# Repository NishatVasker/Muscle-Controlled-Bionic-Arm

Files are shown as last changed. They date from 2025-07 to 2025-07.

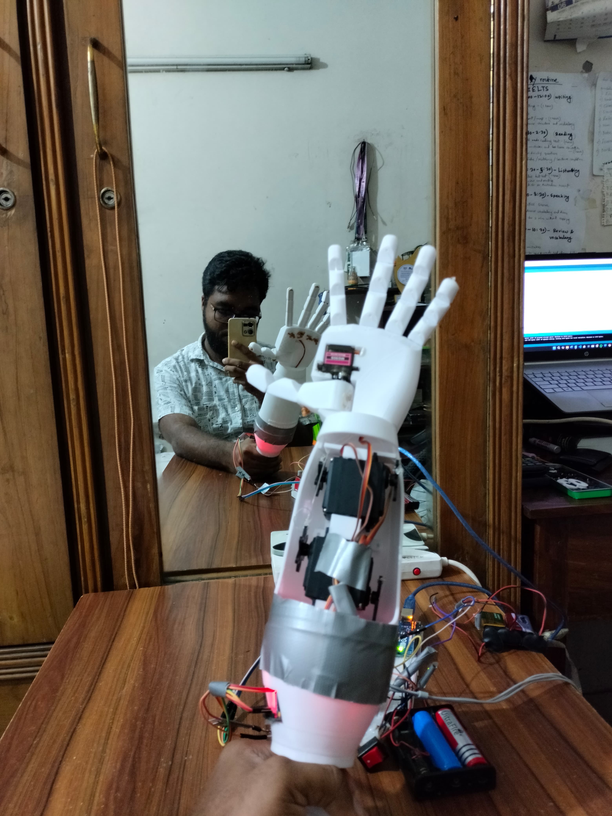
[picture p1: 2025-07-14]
Image and Video/Bionic_arm_media (1).jpg

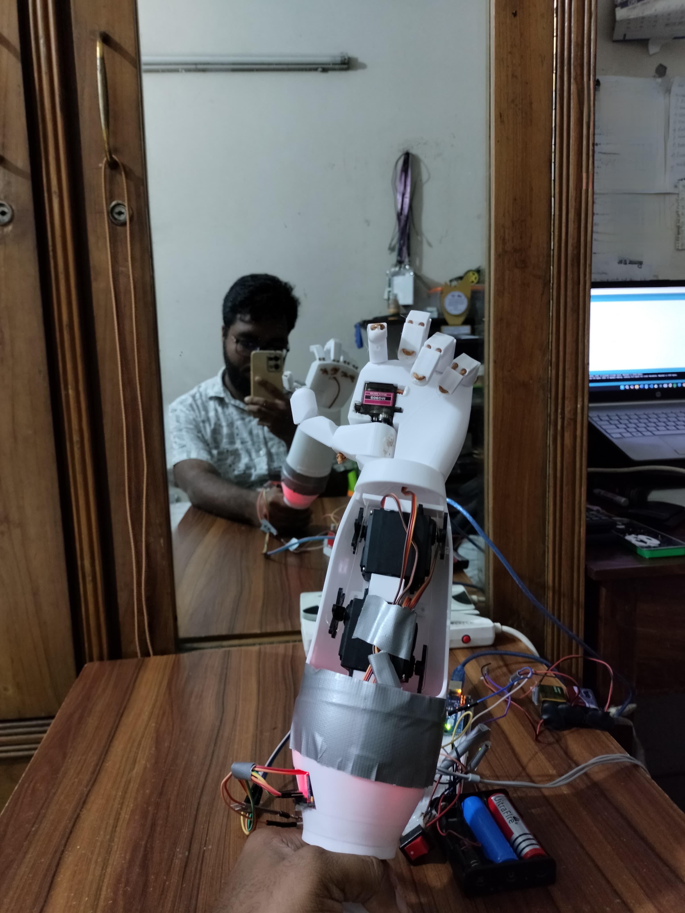
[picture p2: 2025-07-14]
Image and Video/Bionic_arm_media (14).jpg

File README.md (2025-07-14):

# Muscle-Controlled-Bionic-Arm
# 💪 EMG-Controlled Bionic Arm | Arduino + Muscle Sensor + 3D Printed

This open-source project demonstrates a **bionic arm controlled via EMG (Electromyographic) muscle signals**, designed for two core applications:

1. Assisting **people without a left arm** as a low-cost prosthetic solution.  
2. Serving as a functional **robotic limb for humanoid robots**.

The system uses **muscle signals** from a forearm to control **five servo motors** that replicate human hand motions in real-time.

Bionic_arm_media (11)

---

## 🎯 Features

- EMG-based real-time motor control using Arduino  
- Five degrees of motion via MG996R servos  
- PCA9685 for efficient servo signal handling  
- Fully 3D printed modular arm (lightweight, 400g)  
- Cost-effective and prosthetic-friendly design  
- Can be extended for humanoid robotics

---

## 🧰 Components Used

| Component | Description / Quantity |
|---|---|
| Arduino Uno | Microcontroller (1x) |
| MG996R Servo Motors  | High-torque motors (5x) |
| PCA9685 Servo Driver | 16-channel PWM driver (1x) |
| EMG Muscle Sensor | Generic sensor (1x) |
| 9V Batteries | For EMG sensor power (2x) |
| 3D Printed Arm | PLA, 30% infill, total ~400g |
| Jumper Wires | For connections |

---

## 🧠 How It Works

- EMG sensor detects electrical activity from your forearm muscles.  
- Arduino reads the EMG signal as analog input.  
- Signal is mapped to servo angles using threshold-based control.  
- PCA9685 generates PWM signals for servo motors.  
- Servo motors rotate fingers/wrist to mimic hand movement.

---

## 🔌 Full Wiring Connections

This section details all the electrical connections between the microcontroller, sensor, servo motors, servo driver, and batteries. It assumes you're using an **Arduino Uno**, **5 MG996R servos**, **a PCA9685 servo driver**, and a **generic EMG muscle sensor** powered by two 9V batteries.

---

### 🧠 EMG Sensor → Arduino Uno

| EMG Sensor Pin | Connects To |
|---|---|
| VCC | +9V Battery 1 |
| GND | GND of Battery 1 and Arduino GND |
| SIG (OUT) | Arduino A0 (Analog Input)  |

> 🔋 Power the EMG sensor using **two 9V batteries in series** for ±9V operation (as many analog EMG modules require). Ensure the Arduino shares a **common ground** with the battery.

---

### 🔧 PCA9685 Servo Driver → Arduino Uno (I2C)

| PCA9685 Pin | Arduino Uno Pin |
|---|---|
| VCC | 5V |
| GND | GND |
| SDA | A4 |
| SCL | A5 |

> 🧠 This sets up I2C communication for servo control.

---

### ⚙️ Servo Motors (MG996R) → PCA9685 Channels 0–4

| Servo | PCA9685 Channel | Signal Pin | VCC (Red) | GND (Brown) |
|---|---|---|---|---|
| Thumb Servo | 0 | CH0 | 5V Power  | Common GND  |
| Index Servo | 1 | CH1 | 5V Power  | Common GND  |
| Middle Servo  | 2 | CH2 | 5V Power  | Common GND  |
| Ring Servo | 3 | CH3 | 5V Power  | Common GND  |
| Wrist Servo | 4 | CH4 | 5V Power  | Common GND  |

> ⚠️ Do **not power servos from Arduino 5V pin**. Use a **separate 5V–6V external power source** (e.g., 2-cell Li-ion battery or 5V/3A adapter) to VCC of PCA9685 servo rail.

---

### 🔋 Power Supply Summary

| Device | Power Source | Notes |
|---|---|---|
| Arduino Uno | USB or 9V adapter | Can be USB-powered during testing |
| PCA9685 (logic)  | Arduino 5V | Connected via VCC pin |
| Servo Motors | External 5–6V (2–5A) | Do not use Arduino 5V for servos |
| EMG Sensor | Two 9V batteries (±9V) | Sensor output to Arduino A0 |

---

### 🧷 Common Ground Wiring (Very Important!)

You **must connect all GNDs together**:
- Arduino GND
- PCA9685 GND
- EMG sensor GND
- Servo motor power GND
- 9V battery GND (used in EMG)

This ensures a stable reference voltage for analog signal reading and PWM control.

---

### 🖼️ Suggested Diagram (Optional, generated with GPT from microcontroller code)

 

---

## 📐 Mathematical Mapping

Let `V_emg` be the EMG analog signal. The angle θ for servo is calculated as:

- If `V_emg < 250`, then `θ = 0°`  
- Else, map `V_emg` from 250–600 to 0–180°

```cpp
if (V_emg > threshold) {
  angle = map(V_emg, 250, 600, 0, 180);
} else {
  angle = 0;
}
```  

## 🧾 Pseudocode
Start
Initialize I2C and PCA9685
Loop:
    Read EMG signal from A0
    If signal > threshold:
        Map signal to angle
        Move all 5 servos to that angle
    Else:
        Set servos to 0°
Repeat

## 📹 Video

🎥 Watch the Bionic Arm in Action:  
➡️ [https://www.youtube.com/shorts/qkh9qTzFNlg](https://www.youtube.com/shorts/qkh9qTzFNlg)

https://github.com/user-attachments/assets/264a68eb-bbef-4f23-b577-94a843c432ea

Bionic_arm_media (11)
Bionic_arm_media (6)
Bionic_arm_media (5)

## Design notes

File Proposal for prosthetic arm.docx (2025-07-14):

## Prosthetic Arm Controlling with EMG Muscle Sensor

### 1. Title

Smart, Affordable Prosthetic Arm: A 3D-Printed Muscle-Controlled Assistive System for Human and Robotic Use

### 2. Introduction

Prosthetic limbs are critical tools for individuals who have suffered limb loss, enabling them to regain essential functionality and independence. However, advanced prosthetic technologies often remain inaccessible due to high costs and limited availability in developing regions. This project proposes a cost-effective, 3D-printed prosthetic arm controlled via electromyography (EMG) muscle sensors. It is designed to be functional, affordable, and accessible for both human and robotic applications.

### 3. Uniqueness of the Project

- Fully 3D-printed design with a weight of 400g and modular assembly.
- Integrated with a high-quality EMG sensor that interprets muscle movement into real-time servo control.
- Uses open-source components and code, promoting educational and research use.
- Designed to serve both amputees and robotic platforms, which is rare in low-cost prosthetics.
- Utilises standard MG996R and MG90S servo motors for mechanical actuation, with tendons formed from fishing line and paracord.

### 4. Research Gap

- Most low-cost prosthetic solutions lack intuitive EMG control.
- Current open-source robotic hand models are not typically adapted for real-world prosthetics.
- Limited research on EMG-controlled arms that are 3D-printed, modular, and open-source, particularly with affordable hardware suited for developing countries.

### 5. Market Value and Usefulness

- For amputees: Provides basic hand functionality such as grasping, pinching, and releasing.
- In robotics: Serves as a human-like actuator controlled via EMG or other signals for gesture replication.
- In education: Enables students to explore concepts in biomedical engineering, mechatronics, and robotics.
- Market potential: High in countries with limited access to advanced prosthetics. Potential for NGOs, assistive tech startups, and robotics labs.

### 6. Integration for Humans and Robots

- Human use: Surface EMG electrodes are placed on the forearm muscles. Signals are read and translated into joint movement using an Arduino.
- Robotic use: The EMG input can be replaced with digital or AI-based signals, allowing it to act as a programmable robotic manipulator.

### 7. Manufacturing Process

Step | Description
3D Design | Used open-source design from grossrc
3D Printing | PLA filament, 10–30% infill, ~400g
Mechanical Assembly | 5 servo motors, tendon routing, glue
Electrical Setup | Arduino Uno, PCA9685 driver, EMG sensor
Coding and Signal Processing | Arduino IDE, EMG input filtering
Testing | Manual and EMG signal test via servo tester

### 8. Components and Specifications

Component | Specification | Quantity | Source
MG996R Servo Motor | Torque ~1.2–1.5 Nm, 180° rotation | 4 | RoboticsBD
MG90S Micro Servo | 180° rotation, lightweight finger control | 1 | RoboticsBD
Arduino Uno R3 | ATmega328P Microcontroller | 1 | RoboticsBD
PCA9685 16-Channel Servo Driver | 12-bit PWM resolution | 1 | RoboticsBD
EMG Muscle Sensor Kit | Surface electrodes, signal conditioner | 1 | RoboticsBD
Breadboard, Wires, USB Cable, Glue Stick,etc | Standard electronics | Various | RoboticsBD
3D Printed Hand | Humanoid design from grossrc (Thingiverse) | 1 | Local print

### 9. Pseudocode for Control Logic

Start System

Initialize Arduino, EMG Sensor, PCA9685, Servo Pins

LOOP:

Read analog EMG signal from muscle sensor

IF signal > threshold:

Normalize signal to angle range (0–180)

Map angle to corresponding servo for finger movement

Send angle as PWM output to each servo via PCA9685

ELSE:

Set all servos to rest position

End Loop

## 9. Analytical and Logical Control Design for EMG-Controlled Prosthetic Arm

### 9.1 System Logic Overview

The control loop transforms human muscle signals into finger movement using signal processing, linear mapping, and servo actuation.

#### Signal Flow Architecture:

1. EMG Sensor (Analogue Signal)

↓

2. ADC Conversion (10-bit: 0–1023)

↓

3. Noise Filtering (EMA Filter)

↓

4. Signal Thresholding (rest vs active)

↓

5. Normalisation to intensity (0–1)

↓

6. Mapping intensity to servo angle (0°–180°)

↓

7. Convert angle to PWM (pulse width)

↓

8. Servo actuation via PCA9685

### 9.2 Mathematical Breakdown

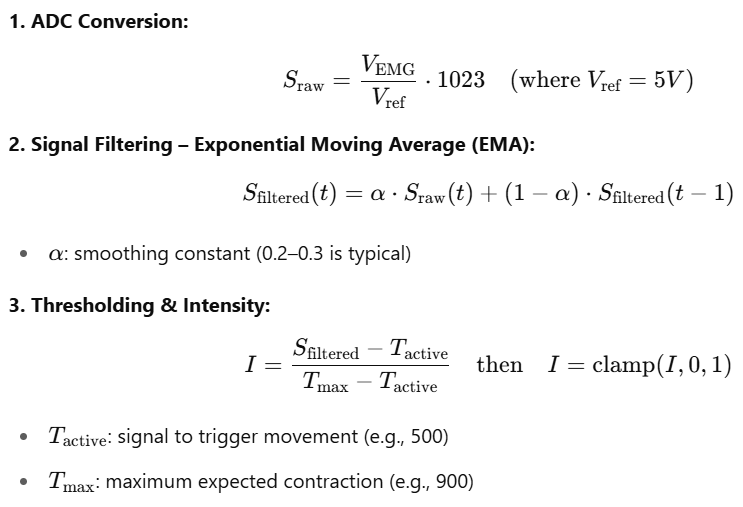
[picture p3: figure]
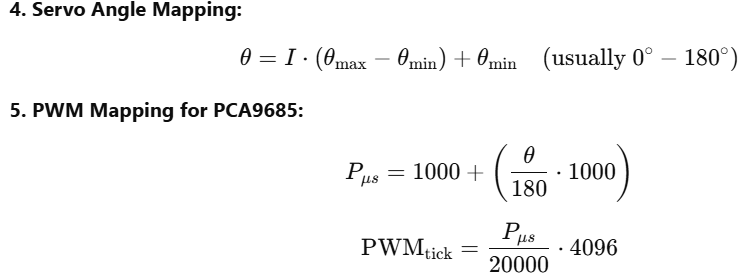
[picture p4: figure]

### 9.3 Final Control Logic – Pseudocode

START

// --- INITIALISATION ---

Set EMG_input_pin = A0

Set smoothing_alpha = 0.2

Set θ_min = 0°, θ_max = 180°

Set PWM_min = 1000 μs, PWM_max = 2000 μs

Set threshold_rest = 400

Set threshold_active = 500

Set signal_max = 900

Initialize PCA9685 (I2C)

Attach servos to channels: [thumb, index, middle, ring, pinky]

Set all servos to neutral (90°)

// --- MAIN LOOP ---

Loop Forever:

// Step 1: Read EMG analog value

raw_signal = analogRead(EMG_input_pin)

// Step 2: Apply Exponential Moving Average Filter

filtered_signal = (smoothing_alpha × raw_signal) + ((1 - smoothing_alpha) × filtered_signal_previous)

filtered_signal_previous = filtered_signal

// Step 3: Check if signal is above rest threshold

If filtered_signal < threshold_rest:

Set all servos to rest (θ = 90°)

continue

// Step 4: Calculate contraction intensity

intensity = (filtered_signal - threshold_active) / (signal_max - threshold_active)

intensity = Clamp between [0, 1]

// Step 5: Convert intensity to angle

θ = θ_min + intensity × (θ_max - θ_min)

// Step 6: Convert angle to pulse width

P = PWM_min + (θ / 180) × (PWM_max - PWM_min)

PWM_tick = (P / 20000) × 4096

// Step 7: Send PWM tick to all servos

For each servo in [thumb, index, middle, ring, pinky]:

Set PWM_tick on corresponding PCA9685 channel

// Step 8: Small delay to avoid jitter

delay(10 ms)

END LOOP

END

### 9.4 Engineering Notes and Optimisations

#### Dynamic Signal Ranges:

- Muscle strength varies per user. Calibration can be performed by taking average resting EMG for 5 seconds and setting that as threshold_rest.

#### Safety Enhancements:

- Implement watchdog timers: If signal drops or noise spikes > 1 sec, reset system.
- Limit servos between 10° and 170° to avoid binding.

#### Multichannel EMG (Advanced Scope):

- For advanced versions, use multiple EMG sensors to differentiate thumb and finger contractions.

### 9.5 Numerical Example

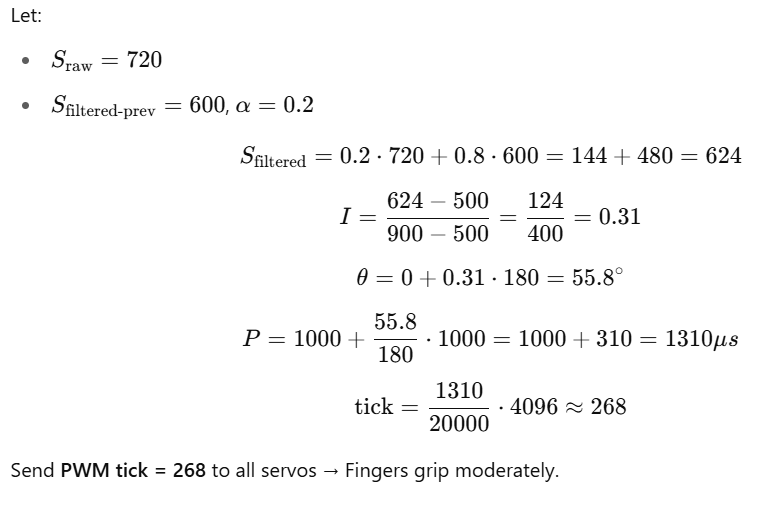
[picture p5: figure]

### 10. Mathematical Analysis

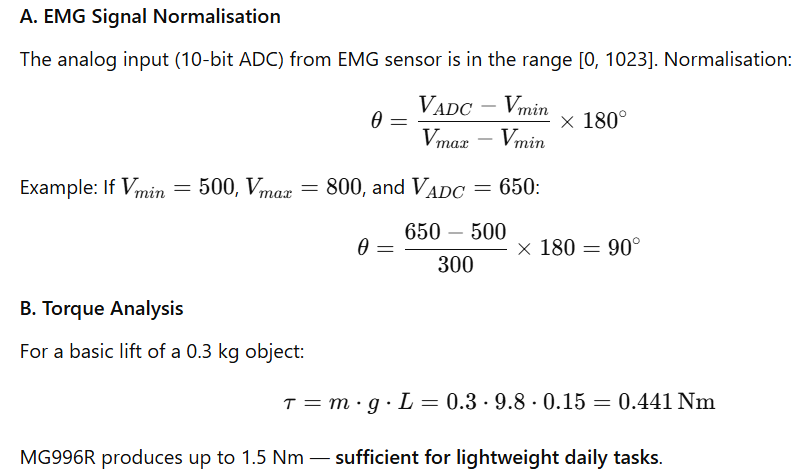
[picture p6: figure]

### 11. Budget Summary

Item Category | Cost (BDT)
Electronics (purchased) | 6,862
3D Printing (400g arm) | 4,000
Miscellaneous (tools, glue) | 2000
Total Cost | 12,862

( This price can be changed anytime due to high pricing of shipment from CHINA)

### 12. Conclusion

This project demonstrates a cost-effective, functional prosthetic arm that uses EMG muscle signals for natural control. Its affordability, modularity, and open-source nature position it as a valuable innovation in both healthcare and robotics. The system can be enhanced with gesture recognition, AI algorithms, or remote robotic integration, offering future development opportunities.

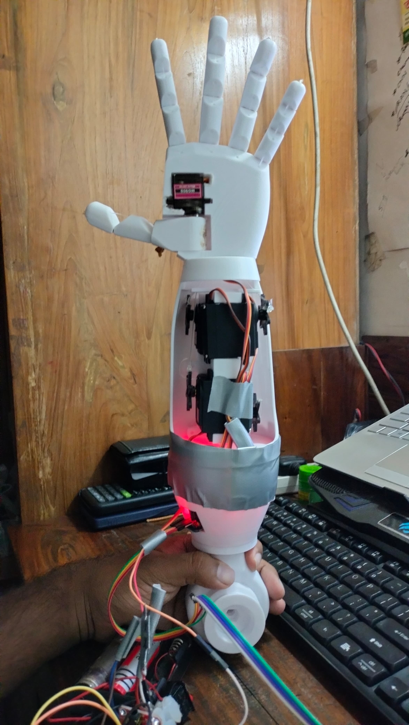
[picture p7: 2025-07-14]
Image and Video/Bionic_arm_media (9).jpg

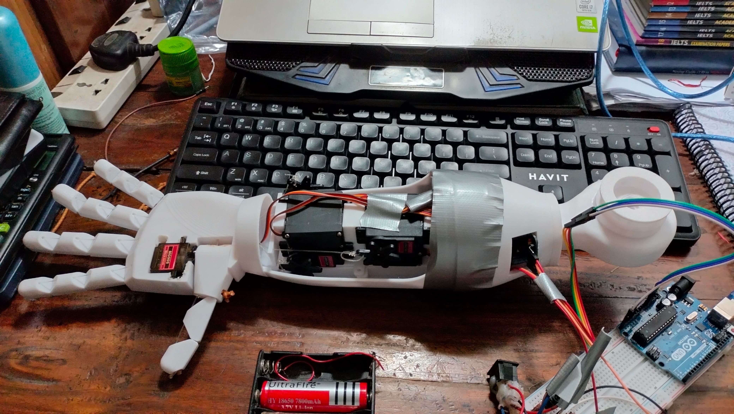
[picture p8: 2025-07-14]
Image and Video/Bionic_arm_media (11).jpg

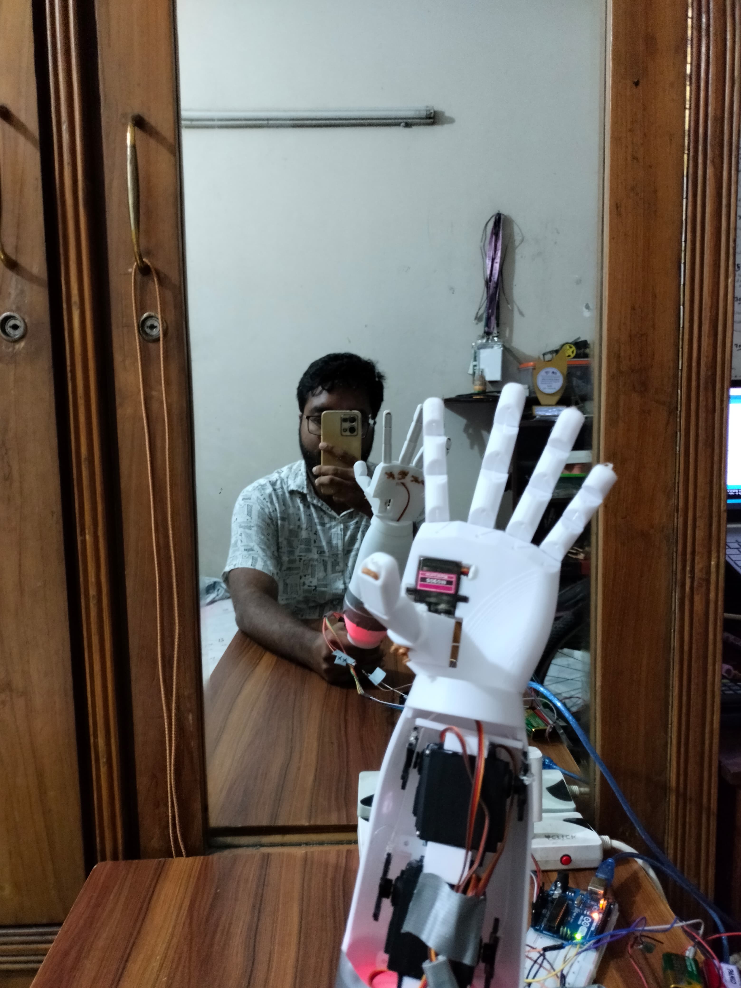
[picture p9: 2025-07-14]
Image and Video/Bionic_arm_media (4).jpg

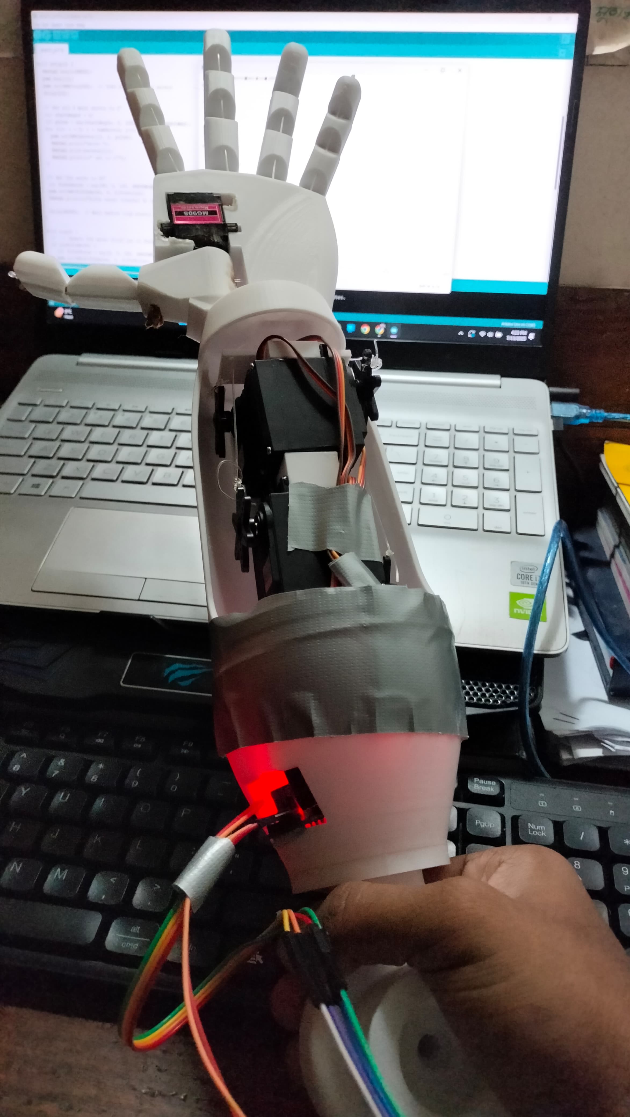
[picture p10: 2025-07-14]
Image and Video/Bionic_arm_media (10).jpg

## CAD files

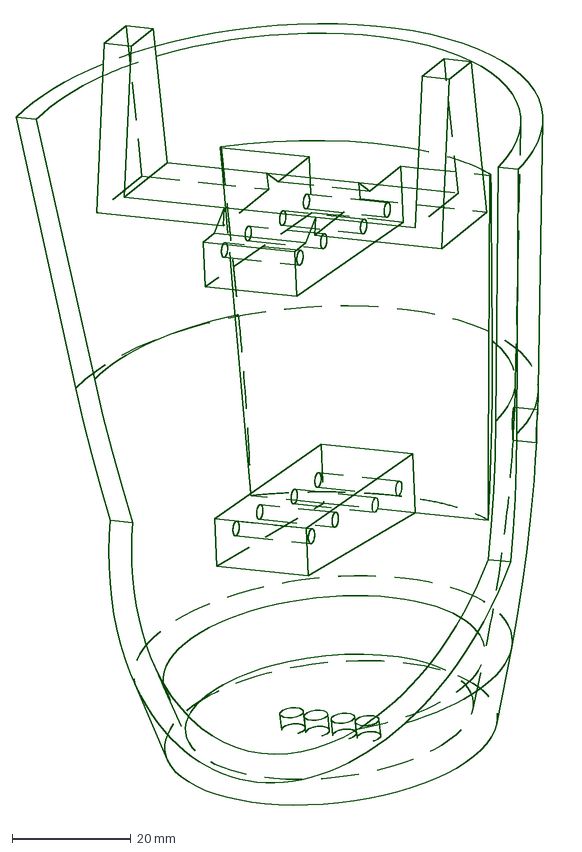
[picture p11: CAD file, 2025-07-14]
files/Piece_1.dxf
92.4 x 133.9 mm

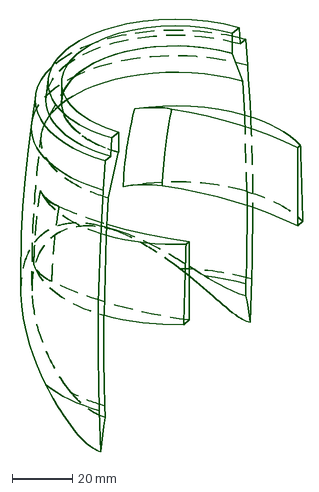
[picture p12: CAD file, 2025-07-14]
files/PC2-2_Cover.dxf
95.2 x 144.6 mm

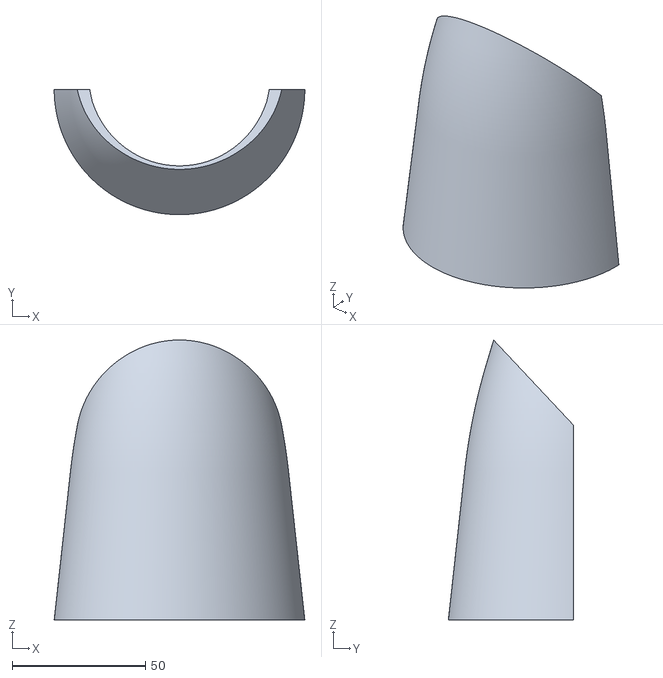
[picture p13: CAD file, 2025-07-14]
files/PC1_Cover.stl
94.0 x 47.0 x 105.0

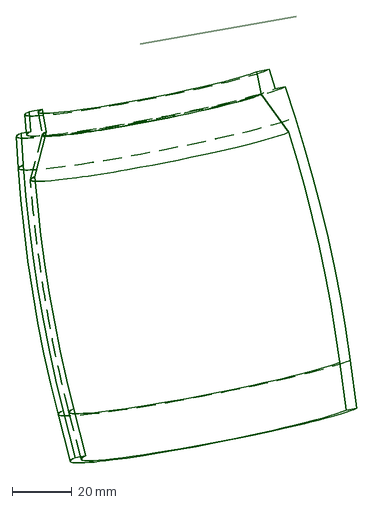
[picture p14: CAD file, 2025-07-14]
files/Piece_2.dxf
113.6 x 149.6 mm

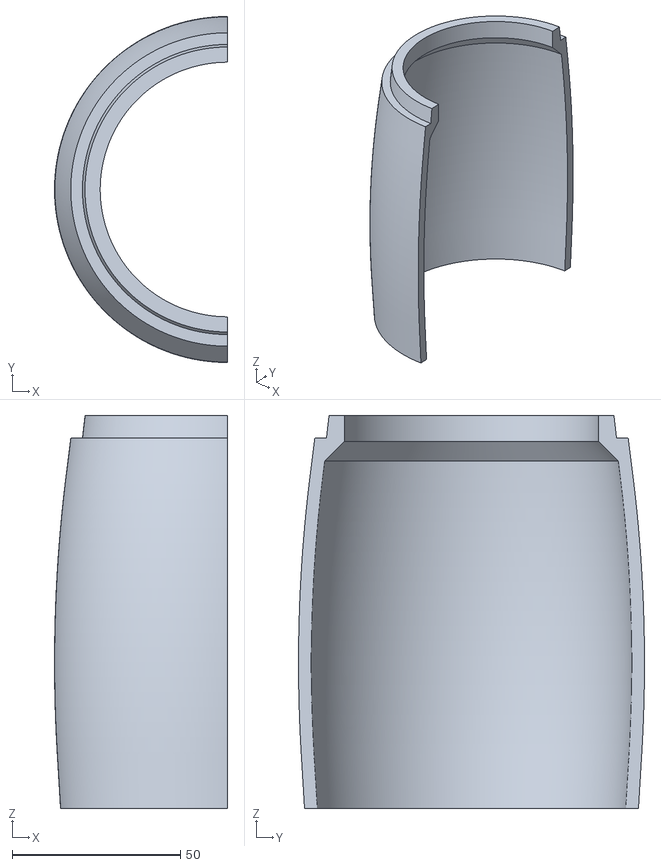
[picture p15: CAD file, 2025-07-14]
files/ArmPiece_2.stl
51.4 x 102.7 x 116.7

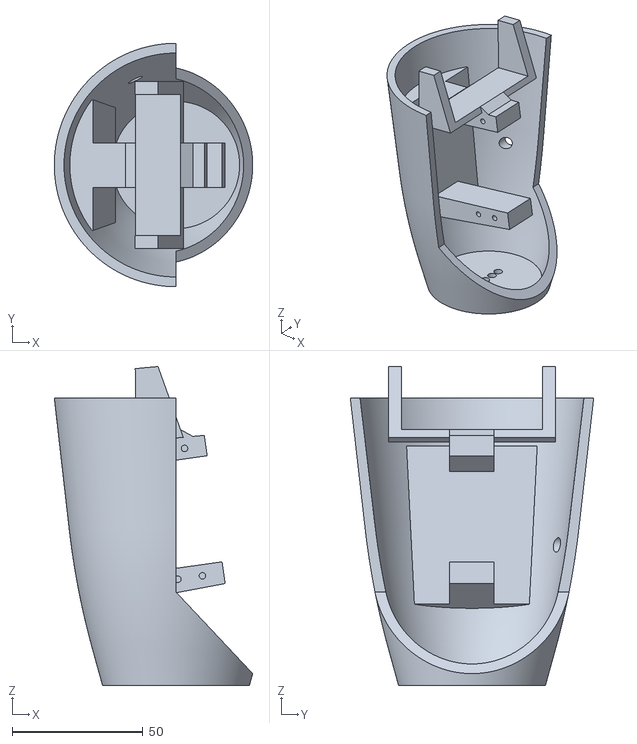
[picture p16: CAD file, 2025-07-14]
files/ArmPiece_1.stl
76.0 x 93.2 x 122.1

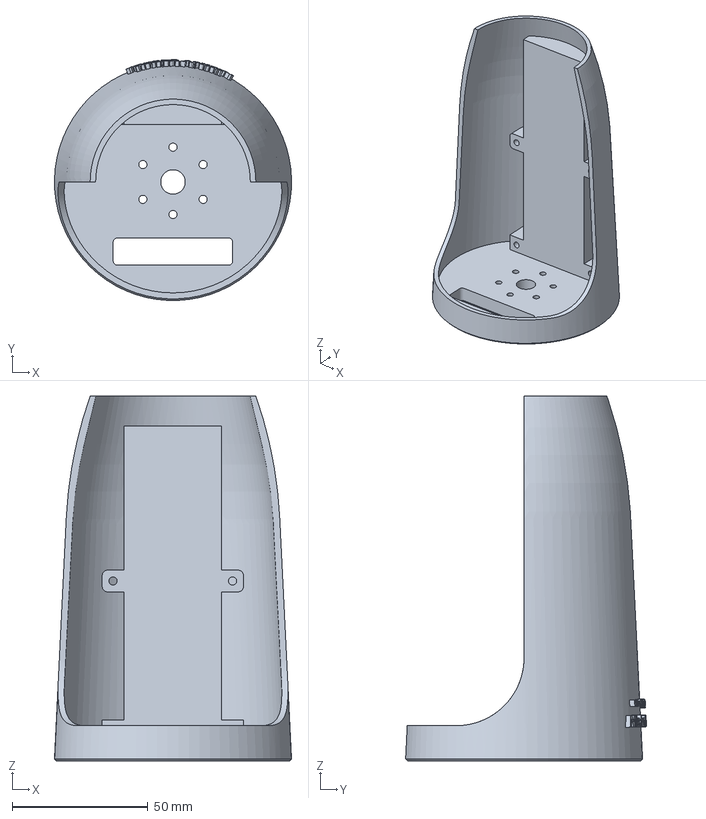
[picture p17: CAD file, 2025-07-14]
files/1.3mf
87.3 x 88.7 x 134.4 mm

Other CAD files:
files/PC1_Cover.dxf

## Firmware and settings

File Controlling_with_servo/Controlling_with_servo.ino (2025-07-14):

#include <Wire.h>
#include <Adafruit_PWMServoDriver.h>

// Create PWM driver instance
Adafruit_PWMServoDriver pwm = Adafruit_PWMServoDriver();

// Pulse width range for standard servos
#define SERVOMIN  150   // Pulse for 0 degrees
#define SERVOMAX  600   // Pulse for 180 degrees

// Main 4 servos (channels 0–3)
const int servos[] = {0, 1, 2, 3};
const int numServos = sizeof(servos) / sizeof(servos[0]);

// 5th servo on channel 4
const int fifthServo = 4;

// Track 5th servo position state
bool isFifthAt90 = true;

void setup() {
  Serial.begin(9600);
  pwm.begin();
  pwm.setPWMFreq(50);  // 50Hz frequency for servos
  delay(10);

  // Set all 4 main servos to 0°
  int startAngle = 0;
  int pulse = map(startAngle, 0, 180, SERVOMIN, SERVOMAX);
  for (int i = 0; i < numServos; i++) {
    pwm.setPWM(servos[i], 0, pulse);
    Serial.print("Servo ");
    Serial.print(servos[i]);
    Serial.println(" set to 0°");
  }

  // Set 5th servo to 90°
  int fifthPulse = map(90, 0, 180, SERVOMIN, SERVOMAX);
  pwm.setPWM(fifthServo, 0, fifthPulse);
  Serial.println("Fifth servo (channel 4) set to 90°");

  delay(4000);  // Wait before loop starts
}

void loop() {
  // --- Update 5th servo first (so it feels synced) ---
  if (isFifthAt90) {
    int fifthPulse = map(0, 0, 180, SERVOMIN, SERVOMAX);
    pwm.setPWM(fifthServo, 0, fifthPulse);
    Serial.println("Fifth servo set to 0°");
    isFifthAt90 = false;
  } else {
    int fifthPulse = map(90, 0, 180, SERVOMIN, SERVOMAX);
    pwm.setPWM(fifthServo, 0, fifthPulse);
    Serial.println("Fifth servo set to 90°");
    isFifthAt90 = true;
  }

  // --- Now move servos 0–3 to 180° ---
  int angle = 180;
  int pulse = map(angle, 0, 180, SERVOMIN, SERVOMAX);
  for (int i = 0; i < numServos; i++) {
    pwm.setPWM(servos[i], 0, pulse);
    Serial.print("Servo ");
    Serial.print(servos[i]);
    Serial.println(" set to 180°");
  }

  delay(4000);

  // --- Move all servos back to 0° ---
  angle = 0;
  pulse = map(angle, 0, 180, SERVOMIN, SERVOMAX);
  for (int i = 0; i < numServos; i++) {
    pwm.setPWM(servos[i], 0, pulse);
    Serial.print("Servo ");
    Serial.print(servos[i]);
    Serial.println(" set to 0°");
  }

  // Note: 5th servo will toggle again in the next loop()

  delay(4000);
}

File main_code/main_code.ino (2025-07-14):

#include <Wire.h>
#include <Adafruit_PWMServoDriver.h>

Adafruit_PWMServoDriver pwm = Adafruit_PWMServoDriver();

#define SERVOMIN  150
#define SERVOMAX  600

const int servos[] = {0, 1, 2, 3};
const int fifthServo = 4;

const int sensorPin = A1;

// Thresholds (adjust as needed)
const int upperThreshold = 300;  // Arm closed
const int lowerThreshold = 200;  // Arm open (hysteresis)

// Tracking state
bool armClosed = false;

void setup() {
  Serial.begin(9600);
  pwm.begin();
  pwm.setPWMFreq(50);

  moveArm(false); // Start in open position
}

void loop() {
  int avgEMG = readAverageEMG(10);  // Smooth EMG input
  Serial.print("EMG avg: ");
  Serial.println(avgEMG);

  if (!armClosed && avgEMG > upperThreshold) {
    moveArm(true); // Close arm
    armClosed = true;
  } 
  else if (armClosed && avgEMG < lowerThreshold) {
    moveArm(false); // Open arm
    armClosed = false;
  }

  delay(100);  // Adjust for response rate
}

int readAverageEMG(int samples) {
  long total = 0;
  for (int i = 0; i < samples; i++) {
    total += analogRead(sensorPin);
    delay(5);
  }
  return total / samples;
}

void moveArm(bool close) {
  int angle = close ? 180 : 0;
  int pulse = map(angle, 0, 180, SERVOMIN, SERVOMAX);

  for (int i = 0; i < 4; i++) {
    pwm.setPWM(servos[i], 0, pulse);
    Serial.print("Servo ");
    Serial.print(servos[i]);
    Serial.println(close ? " closed" : " opened");
  }

  int fifthAngle = close ? 0 : 90;
  int fifthPulse = map(fifthAngle, 0, 180, SERVOMIN, SERVOMAX);
  pwm.setPWM(fifthServo, 0, fifthPulse);
  Serial.println(close ? "Fifth servo closed" : "Fifth servo opened");
}
